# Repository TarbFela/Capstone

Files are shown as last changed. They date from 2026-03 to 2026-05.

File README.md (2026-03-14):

# A Temperature Programming Power & Control System for Desorption Energy Measurement Experiments

This is my electrical & computer engineering capstone as well as my honors thesis at the University of Maine. The hardware includes a number of power cards driven by PWM signals from a control board. Another board provides a serial interface to a Balzers mass spectrometer QMS 112 interface. The software for this project is largely written for the RP2350 microcontroller (like that found on the Raspberry Pi Pico 2) on a Pimoroni PGA2350 devboard/daughtercard. The PGA2350 plugs into the controller motherboard called ADPC for "Analog and Digital Processing and Control". This board incorporates, in addition to other instrumentation, MCP3462R and MCP3562R ADCs and an ADA4255 PGIA; all three of these provide SPI interfaces. I'm writing drivers for these devices which can be found in `src2/`. Functionalities are loosely (and currently rather haphazardly, with deprecation, poor compartmentalization, etc) broken out into separate headers/source files. 

I'll probably post hardware files somewhere at some point. The READMEs are currently acting as in-progress note-taking and as in-progress documentation. This project is meant to be used after I graduate by researchers in the Frederick Lab at FIRST. The code is roughly written with extensibility in mind.

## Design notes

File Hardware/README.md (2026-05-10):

# Temperature Programming & Control System Hardware

This is a collection of hardware documentation and resources. EasyEDA projects are downloaded and have been parsed by KiCad (do _not_ attempt to fabricate from these KiCad projects; fonts, etc have _not_ carried over). All datasheets used have been added. Any written hardware documentation is included.

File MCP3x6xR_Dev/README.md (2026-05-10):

# MCP3x6xR Development

Development for ADC-facing code on the ADPC board. 

Note that symlinks to the driver code need to be instantiated; git does not do this.

A `script.py` file is included to automate the serial interfacing tasks (as opposed to using a serial monitor);
this script also decodes the raw data stream. It takes as an argument the path of the usb device; on MacOS this is
something like `/dev/cu.usbmodem####`.

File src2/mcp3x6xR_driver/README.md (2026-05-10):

# MCP3x6xR Driver for RP2040/RP2350 [WIP]
This is a simple driver for the MCP3x6xR series ADCs that I will employ in my capstone project. They are SPI devices and I am using RP2350-based boards (namely, the Pimoroni PGA2350).

The driver abstracts basic SPI interactions and provides macros for the register addresses, command structure, and register fields for these ADCs. 
There is also a PIO program and corresponding driver to perform triggered reads of the ADC in continuous read mode. 
Functions pass ownership of GPIO pins between RP2350 SPI and PIO machines.

### Annoying, Sneaky Hardware Requirement
This series of ADCs seems to _require_ that the nIRQ pin be pulled to logic high externally. 
Without this step, the **ADC WILL NOT PERFORM CONVERSIONS**.

## Example Code

The `MCP3x6xR_Dev` directory has an example project using this driver. This project is based around a board I've designed called the ADPC;
if you intend to run this program on your own board you will have to define the RP2350 GPIO pins with `#define ADC_1_PIN_<name> <number>` and remove the references
to `ADPC_cfg.h` (you may even replace it with your own `<>_cfg.h`). 

The example code interfaces with a computer over USB; any serial port tool should work.
The device uses an ASCII interface except when collecting data, when it streams raw bytes over USB CDC. 
Providing a `"q"` input puts the RP2350 back in USB flash mode for further programming. 

`script.py` automates this interface. It requires that you know the path of the USB serial device (on MacOS this is `/dev/cu.usbmodem####`).

`graphing.py` graphs the received data. 

## Structure
This is a work in progress. I am still sorting out how best to define the types and how to structure functions, etc.

I perused the datasheet and wrote defines for a bunch of registers, addresses, etc based on information found therein. While some industry-standard headers (such as those from Raspberry Pi in their hardware/regs headers) use a structure wherein masks, LSB & MSB, and some values are provided for register fields, I am instead opting to provide OR-able field values. For example, in order to construct a value to be written to configuration register 0, you would simply:

```
uint8_t reg_val = MCP_CFG0_VREF_SEL_INTERNAL | MCP_CFG0_NO_PARTIAL_SHUTDOWN | MCP_CFG0_CLK_SEL_INTERNAL | MCP_CFG0_CURRENT_BIAS_SEL_0u0A | MCP_CFG0_ADC_MODE_STDBY;
```

_(In this particular case, some of these values are unnecessary. Some, however, are necessary, as a default value of 0 in those fields would cause a partial shutdown, e.g.)_

### Abstractions

The following functionalities have since been abstracted into higher-level functions (e.g. `mcp_write_regs()`)

### Reading and Writing

Reading and writing to registers requires a corresponding command type value in the command type field of the command byte. Most command types are 6 bits, but with read/write commands the top four bits correspond instead to the address information. For this reason I've structured the macros such that the read and write commands take an argument corresponding to the address of interest. An example command byte to perform a static (non-incrementing) read of configuration register 2 would be constructed like so:

```
uint8_t cmd = MCP_CMD_DEV_ADDR | MCP_CMD_ADC_REG_READ_STAT(MCP_REG_ADDR_CONFIG2);
```

### ADC MUX Input Selection

A similar macro to the one described above is used to select ADC inputs. Since each ADC input (+/-) may select from any of 15 sources and since the corresponding mux field values are the same between the positive and negative inputs, mux selection is done accordingly:

```
MCP_MUX_P_SEL(MCP_MUX_VAL_CH4) | MCP_MUX_N_SEL(MCP_MUX_VAL_CH0)
```

### Function return values

Because these ADCs read out their status while receiving the command byte, all ADC SPI commands are structured to return an `mcp_status_t` (name might change to be more specific). This is a single byte. Another function might be written to parse this byte. Bitfields are defined as `MCP_STAT_<...>`.

### A Note About Error Handling

Some effort has been made to catch loss of communication with the ADC. However, this was not a comprehensive effort by any means, so the behavior of the driver when communication is lost (e.g. if the ADC loses power) is thoroughly undefined!

## PIO

Included here is a PIO program to operate the device in continuous read mode, wherein the nIRQ pin on the ADC is pulled low when a conversion is ready. This triggers the PIO to initiate a SPI read (i.e. the PIO machine sends out 32 clock cycles and shifts the MISO data into a fifo). DMAs are daisy-chained. A globally accessible DMA buffer (`dma_buff_adc_0`) is provided. It is aligned such that the DMAs should automatically wrap upon filling their respective halves of the buffer. **It is important that the DMAs be provided an interrupt handler to clear interrupts**. See an example below:

```
void dma_irq_handler_1(void) {
    // clear the correct interrupt
    int culprit_is_a = dma_hw->ints0 & (1u << mpio_1.dma_a);
    if (culprit_is_a) {
        dma_hw->ints0 = 0x1 << (mpio_1.dma_a);
    }
    else {
        dma_hw->ints0 = 0x1 << (mpio_1.dma_b);
    }
}
```

### Start and stop functions

Start and stop functions are provided which _only_ enter or exit PIO mode. These functions **only** perform configuration tasks (e.g. for pins, dmas, pio, and spi) but do not communicate with the ADC. A separate SPI command should be sent to initiate conversions; once the nIRQ is pulled low, data is (likely) ready and the PIO start() function can be called. **KEEP CS ACTIVE AFTER THE SPI READ COMMAND!** (as per the datasheet).

```
    // write ADC mode
    uint8_t tx[2], rx[2];
    tx[0] = MCP_CMD_DEV_ADDR | MCP_CMD_ADC_REG_WRITE_INCR(MCP_REG_ADDR_CONFIG0);
    tx[1] = MCP_CFG0_VREF_SEL_INTERNAL | MCP_CFG0_NO_PARTIAL_SHUTDOWN | MCP_CFG0_CLK_SEL_INTERNAL | MCP_CFG0_ADC_MODE_CONV;
    gpio_put(ADC_1_PIN_CS,0); sleep_us(MCP_SLEEPTIME_US);
    spi_write_read_blocking(spi1, tx, rx, 2);
    sleep_us(MCP_SLEEPTIME_US); gpio_put(ADC_1_PIN_CS,1);
    // prepare to perform static read of ADC register
    tx[0] = MCP_CMD_DEV_ADDR | MCP_CMD_ADC_REG_READ_STAT(MCP_REG_ADDR_ADCDATA);
    // wait for first IRQ pin signal
    while(!gpio_get(ADC_1_PIN_IRQ)) tight_loop_contents();
    gpio_put(ADC_1_PIN_CS,0); sleep_us(MCP_SLEEPTIME_US);
    // perform first read.
    spi_write_read_blocking(spi1, tx, rx, 1);

    mcp_pio_start(&mpio_1);
```

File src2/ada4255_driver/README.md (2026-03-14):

# ADA4255 Driver for RP2040/RP2350 [WIP]

This is a simple SPI driver for the ADA4255 programmable-gain instrumentation amplifier (PGIA) that I am using as a thermocouple front-end for my thesis project.

## ADA4255 Command Structure

Refer to the ADA4255 datasheet for any further details. The command interface is very simple; there are two bytes (a third if you are use CRC; I don't wanna) where the first contains:

1. A read/write bit
2. A register address

And the second bit contains the data, streamed either of MOSI or MISO depending on the R/W bit provided in the previous byte.

This driver provides macros for all registers and fields (WIP: not actually done yet!). To figure out what they actually do, see the datasheet.

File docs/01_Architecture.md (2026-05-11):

# System Architecture

This document describes how the pieces fit together — both the hardware boards and the firmware layers within them. Read this before [`03_Driver_Reference.md`](03_Driver_Reference.md) or any of the deeper documents.

---

## The hardware stack

```
   ┌────────────────────────────┐         ┌────────────────────────────┐
   │          ADPC               │  UART  │           MSIF              │
   │   (control + measurement)   │◄──────►│   (mass spec interface)    │
   │                             │         │                            │
   │     PGA2350 (RP2350)        │         │     PGA2350 (RP2350)       │
   │     + 2× MCP ADCs           │         │     + DAC + ADC frontend   │
   │     + ADA4255 PGIA          │         │                            │
   └─────────────┬───────────────┘         └─────────────┬──────────────┘
                 │                                       │
        PWM ×12, PH_EN ×6                                │
                 │                          QMS-112 remote-control
                 ▼                                       ▼
   ┌─────────────────────┐   ┌─────────────────────┐    ┌──────────────────┐
   │     MPHB-002 #1     │   │    MPHB-002 #2 ...   │    │   Balzers QMS    │
   │  (2 buck converters │   │                      │    │      QMS-112     │
   │   per board, "1A"   │   │                      │    │ mass spectrometer│
   │   and "1B")         │   │                      │    │                  │
   └──────────┬──────────┘   └──────────────────────┘    └──────────────────┘
              │
              ▼
        ┌──────────┐
        │  HEATER  │ (load sits between the two buck converter outputs)
        └──────────┘
```

### The boards

**ADPC** — *Analog and Digital Processing and Control.* Hosts a PGA2350 daughtercard (the actual microcontroller, an RP2350) plus three precision SPI chips:

| Chip | Function | Notes |
|---|---|---|
| MCP3462R | 16-bit ADC — current sensing (ISNS) | Faster sample rate; this is the one in the control loop |
| MCP3562R | 24-bit ADC — temperature & voltage sensing (TSNS, VSNS) | Higher precision; scan mode across multiple inputs |
| ADA4255 | Programmable-gain instrumentation amplifier | Front-end for the thermocouple before it hits the MCP3562R |

The ADPC also has an MCP9808 I²C temperature sensor and a TS3A24159 analog switch for voltage-sense amp gain selection.

**MPHB-002** — *Multi-Phase H-Bridge, revision 002.* The power stage. Each MPHB-002 board provides **two** "B-style" channels (e.g. `1B` and `2B`). What we call an "H-bridge" here is actually **two buck converters with the load between them** — this lets us drive the heater both positively and negatively about a common-mode level. Up to three boards can be installed, giving six independent channels (`HB1A`, `HB2A`, `HB3A`, `HB1B`, `HB2B`, `HB3B`).

Each channel exposes:
- **Two PWM inputs** (`A` and `C`, conceptually one for each buck converter half)
- **One phase-enable input** (`PH_EN`) that turns the power stage on/off without changing PWM
- **Current-sense output** wired back to the ADPC's MCP3462R

**MSIF** — *Mass Spec Interface.* Communicates with a Balzers QMS-112 mass spectrometer via that instrument's "QDP" remote-control connector. Hosts its own PGA2350 plus analog I/O front-ends for the QMS-112's analog signals (FMASS+, etc.) and digital handshake lines (EMIS_OK, etc.). Currently a stub — see [`06_Extending_MSIF_UART.md`](06_Extending_MSIF_UART.md).

---

## The firmware stack (ADPC side)

The firmware is organized into roughly four layers, from low-level hardware drivers up to the user-facing shell. Each layer builds on the one below; you can usually do new work at one layer without disturbing the others.

```
  Layer            File(s)                              Purpose
  ─────────────────────────────────────────────────────────────────────────────
   USER SHELL     adpc_data_streaming.c                 main(), boot, reboot
                  adpc_app.[ch]                         line buffer, dispatch
                                                                  
   COMMANDS       adpc_app_funcs.[ch]                   isp, ictl, rstream,
                                                        irun, irun stream,
                                                        adpc_init
                                                                  
   CONTROL LOOP   adpc_core1.[ch]                       runs on core 1:
                                                        PI current controller
                                                                  
   DRIVERS        ADPC_Dev/ADPC_ADC.[ch]                MCP ADC config
                  ADPC_Dev/adpc_gpio_pwm.[ch]           MPHB PWM / PH_EN
                  ADPC_Dev/adpc_vsns.[ch]               VSNS amp gain pin
                  mcp3x6xR_driver/mcp3x6xR.[ch]         raw SPI to ADC
                  mcp3x6xR_driver/mcp_pio.[ch]          PIO + DMA streaming
                  mcp3x6xR_driver/mcp_pio.pio           PIO assembly program
                  ada4255_driver/ada4255.[ch]           raw SPI to PGIA
                                                                  
   PIN MAP        ADPC_Dev/ADPC_cfg.h                   every #define for a pin
```

`ADPC_cfg.h` is the single source of truth for which physical pin does what. Any new feature that touches a pin should reference symbols from this file, not hardcoded GPIO numbers.

---

## What runs where: cores

The RP2350 has two CPU cores. This firmware uses both:

- **Core 0** — runs `main()`. Owns the USB CDC connection (the shell), the DMA interrupt handlers (which deposit data into RAM), and all "slow" command handling. Lives inside `app_shell_task()` in a loop.
- **Core 1** — *only running when closed-loop current control is active.* Runs `core1_ictl()` which polls the DMA write position, computes a moving-average current, runs a PI controller, and updates the PWM output level. Started/stopped from core 0 via `app_cmd_ictl()`.

The two cores communicate through a hardware FIFO. Core 0 sends `MC_FIFO_STOP_FLAG` to ask core 1 to exit cleanly; core 1 responds with an acknowledgement before exiting.

They also share `ui_state` (declared `volatile`) for things like the current setpoint and the most recently computed level. **Race conditions are a real risk here** — see the hazards document.

---

## What runs where: DMA, PIO, interrupts

The ADC sample path is the heart of the system. Here's the chain, end to end:

```
  ADC pulls nIRQ low ──► PIO state machine wakes up
                         (one per ADC: pio0/sm0 and pio1/sm0)
                                  │
                                  │ shifts 32 clock pulses, captures MISO
                                  ▼
                         PIO RX FIFO has one 32-bit word
                                  │
                                  │ DREQ triggers DMA
                                  ▼
                         DMA writes into ring buffer
                         (dma_a or dma_b, ping-pong, chained to each other)
                                  │
                                  │ when buffer half is full:
                                  ▼
                         DMA fires IRQ on the chosen line
                                  │
                                  │ DMA_IRQ_0 → handler_0   (for ADC 0)
                                  │ DMA_IRQ_1 → handler_1   (for ADC 1)
                                  ▼
                         Handler clears the IRQ flag and updates
                         dma0_last_written / dma1_last_written
                                  │
                                  │ Either core can poll these globals
                                  ▼
                         Consumer (core 0 streaming OR core 1 control)
```

A few subtleties worth knowing now and revisiting in [`05_DMA_PIO_Streaming.md`](05_DMA_PIO_Streaming.md):

- Each ADC gets its **own pair of DMA channels** (A and B), wired as a ping-pong. When A fills, it chains to B and vice versa. Both write into a single contiguous buffer of size `2 × DMA_BUFF_SIZE` so it looks like one circular buffer.
- The buffers are **aligned in memory** to a power-of-two boundary so that DMA *ring mode* automatically wraps the write pointer back to the start of each half. This avoids needing software wrap-around.
- The ADC IRQ pin **must** be pulled high externally — the MCPs won't run conversions otherwise. This trips up most people once.
- `dma0_last_written` is `0` if nothing's been written yet, `1` if buffer A finished, `2` if buffer B finished. Whichever is "current" (i.e. the *other* one) can be inferred.

---

## Data flow during normal operation

The firmware can be in one of several modes. Each is initiated by a shell command:

| Mode | Started by | What core 0 does | What core 1 does | Hardware state |
|---|---|---|---|---|
| Idle | (default after boot) | Shell prompt | not running | PWM off, PH_EN off |
| Initialized | `start` | Shell prompt | not running | PWM running but PH_EN may be off |
| Open-loop level set | `level <n>` | Shell prompt | not running | PWM at fixed differential level |
| Closed-loop current | `ictl` | Shell prompt | PI control on isns | PWM dynamically adjusted |
| Raw data stream | `rstream` | Stream ADC bytes via USB CDC | unchanged | unchanged |
| Program run | `irun` | Step setpoints over time | PI control on isns | PWM dynamically adjusted |
| Program run + stream | `irun stream` | Step setpoints AND stream | PI control on isns | PWM dynamically adjusted |

Note that `rstream` and `irun stream` *do not* alter the control state; they just attach the USB CDC pipe to the DMA buffers and start spitting bytes. The control loop and the streaming output are independent consumers of the same DMA-produced data.

---

## How to think about adding a feature

Pick the layer that matches what you're adding:

| Adding… | Layer | Files to touch |
| --- | ----- | --- |
| A new shell command | USER SHELL → COMMANDS | `adpc_app.c`, `adpc_app_funcs.[ch]` |
| A new mode of using existing peripherals | COMMANDS | `adpc_app_funcs.[ch]` |
| A change to how the controller computes its output | CONTROL LOOP | `adpc_core1.c` |
| A new chip on an existing bus (SPI, I²C) | DRIVERS | new driver folder; reference from `adpc_app_funcs.c` |
| A new pin assignment | PIN MAP | `ADPC_cfg.h` |
| A new high-speed data source (e.g. mass spec ADC over UART) | DRIVERS → COMMANDS | new driver + new app command; see [`06_Extending_MSIF_UART.md`](06_Extending_MSIF_UART.md) |

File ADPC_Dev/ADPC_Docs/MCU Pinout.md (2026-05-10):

# ADPC MCU Pinout (RP2350)

This table lists the pins of the PGA2350, the nets which they are connected to (typically descriptive of devices such as the ADCs, temperature sensors, etc.) and then their appropriate GPIO Function configuration. See the RP2350 Datasheet Section 1.2.3 for reference (replicated in this directory as a CSV). 

## "Notes"
The "Notes" column lists—in addition to some notes—the possibility of some pins to be used as SPI pins.
### SPI Flash Fix
The **bold** entries refer to a plan to use the HB-3B connector (6-pin MPHB-002 connector) as a SPI connector to a W25Q128 flash chip (on a breakout board such as the one produced by Adafruit). This plan requires soldering a wire from an unused PGA2350 pin to an unused HB-B3 pin. This plan may not be necessary if there is adequate storage on the PGA2350's flash chip (also a W25Q128) and if flash writes to this chip do not interfere with other code. This plan would require that the relevant SPI pins only be configured as SPI when the devices on the same spi_n channel are not being used in that way; i.e. when the MCP ADC SPI pins are under "ownership" of the PIO machines which perform data-ready-triggered "SPI" reads. The MCP SPI pins should not attempt to reclaim the SPI pins if their ownership has been transfered to the SPI flash chip. Some construct should be implemented to organize this ownership.

### CS Pins

SPI chip-select pins are configured as GPIO outputs and manually set and reset (with some delay) in code before and after SPI interactions.

### PIO

PIO machines are used to perform triggered SPI-like reads of the two MCP3x62R ADCs. Other ADC communications use the RP2350's SPI blocks. Pin "ownership" is transferred between the two machines according to the `mcp_pio` driver code.

## Pinout

| PIN | NET | FUNCTION | NOTES |
|---|---|:---|---|
| GPIO 0		  | ADC_16_SPI_SDO 		 | SPI0 | |
| GPIO 1		  | ADC_16_MCLK & ADC_24_MCLK 		 | PWM 0A	 | |
| GPIO 2		  | ADC_16_IRQ 		 | SIO / PIO | |
| GPIO 3		  | ADC_16_SPI_SDI 		 | SPI0 / PIO	 | |
| GPIO 4		  | INAMP_GPIO2_CALIB_BUSY 		 | SIO | |
| GPIO 5		  | ADC_16_SPI_CS 		 | SPI0 / SIO |
| GPIO 6		  | ADC_16_SPI_SCK 		 | SPI0 / PIO | |
| GPIO 7		  | INAMP_SPI_CS 		 | SIO | |
| GPIO 8		  | INAMP_GPIO3_FAULT 		 | SIO | |
| GPIO 9		  | ADC_24_IRQ 		 | SIO / PIO | |
| GPIO 10		 | TMP_12C_SDA 		 | I2C1 | |
| GPIO 11		 | INAMP_SPI_SDI & ADC_24_SDI 	 | SPI1 / PIO | |
| GPIO 12		 | INAMP_SPI_SDO & ADC_24_SDO 	 | SPI1		 | |
| GPIO 13		 | ADC_24_SPI_CS 		 | SPI1			 | |
| GPIO 14		 | INAMP_SPI_SCLK & ADC_24_SCLK 	 | 	SPI1 / PIO		 | |
| GPIO 15		 | TMP_12C_SCL 		 | I2C1			 | |
| GPIO 16		 | VSNS_AMP_GAIN_SEL 		 | SIO		 | |
| GPIO 17		 | MPHB_VDET_3 		 | SIO		 | |
| GPIO 18		 | PWM_A_1 		 | PWM 1A			 | SPI0 SCK |
| GPIO 19		 | PWM_C_1 		 | PWM 1B			 | SPI0 TX |
| GPIO 20		 | PWM_B_1 		 | PWM 2A			 | SPI0 RX |
| GPIO 21		 | PWM_D_1 		 | PWM 2B			 | SPI0 CSn |
| GPIO 22		 | PWM_C_2 		 | PWM 3A			 | SPI0 SCK |
| GPIO 23		 | PWM_A_2 		 | PWM 3B			 | SPI0 TX |
| GPIO 24		 | PWM_D_2 		 | PWM 4A			 | SPI1 RX |
| GPIO 25		 | PWM_B_2 		 | PWM 4B			 | SPI1 CSn |
| GPIO 26		 | PWM_B_3 		 | PWM 5A			 | **SPI1 SCK** SPI Flash Fix: HB-3 Pin 2 = SPI SCK |
| GPIO 27		 | PWM_D_3 		 | PWM 5B			 | **SPI TX** SPI Flash Fix: HB-3 Pin 1 = SPI MOSI |
| GPIO 28		 | PWM_A_3 		 | PWM 6A			 | SPI1 RX |
| GPIO 29		 | PWM_C_3 		 | PWM 6B			 | SPI1 CSn |
| GPIO 30		 | MPHB_VDET_2 		 | SIO		 | |
| GPIO 31		 | MPHB_VDET_1 		 | SIO		 | |
| GPIO 32		 | MCU_INDICATOR_LED_1 		 | SIO		 | |
| GPIO 33		 | UART_RX 		 | UART0		 | |
| GPIO 34		 | UART_TX 		 | UART0		 | |
| GPIO 35		 | PH_EN_A2 / MPHB-002 Detect 		 | SIO | SPI0 TX		Open-Drain or Input/Output Low to see 3.3V when MPHB-002 is connected and powered and to PH-disable, resp.  |
| GPIO 36		 | PH_EN_B2 / MPHB-002 Detect 		 | SIO | SPI0 RX		Open-Drain or Input/Output Low to see 3.3V when MPHB-002 is connected and powered and to PH-disable, resp.  |
| GPIO 37		 | PH_EN_B1 / MPHB-002 Detect 		 | SIO | SPI0 CSn		Open-Drain or Input/Output Low to see 3.3V when MPHB-002 is connected and powered and to PH-disable, resp. |
| GPIO 38		 | PH_EN_A3 / MPHB-002 Detect 		 | SIO | SPI0 SCK		Open-Drain or Input/Output Low to see 3.3V when MPHB-002 is connected and powered and to PH-disable, resp. |
| GPIO 39		 | PH_EN_A1 / MPHB-002 Detect 		 | SIO | SPI0 TX		Open-Drain or Input/Output Low to see 3.3V when MPHB-002 is connected and powered and to PH-disable, resp.  |
| GPIO 40		 | PH_EN_B3 / MPHB-002 Detect 		 | SIO | **SPI1 RX** SPI Flash Fix: HB-3 Pin 6 = SPI MISO |
| GPIO 41		 | MCU1_41 		 | _none_			 | **SIO CSn** SPI Flash Fix: HB-3 Pin 5 = SPI CSn (_NOTE: REQUIRES PCB WIRE REWORK!!!_) |
| GPIO 42		 | 12C_HEADER_SDA 		 | I2C1			 | |
| GPIO 43		 | 12C_HEADER_SCL 		 | I2C1			 | |
| GPIO 44		 | MCU_ADC_4 		 | ADC				 | SPI1 RX |
| GPIO 45		 | MCU_ADC_5 		 | ADC				 | |
| GPIO 46		 | MCU_ADC_6 		 | ADC				 | |
| GPIO 47		 | MCU1_47 		 | _none_			 | |
| 3V3		 | MCU_3V3 		 | | |
| 3V3N		 | MCU1_3V3EN 		 | | |
| ADCVRF		  | MCU1_ADCVREF 		 | | |
| BOOTSL		  | MCU1_BOOTSEL 		 | | |
| GND		 | GND 		 | | |
| RUN		 | MCU1_RUN 		 | | |
| SWCLK		 | MCU1_SWCLK 		 | | |
| SWDIO		 | MCU1_SWDIO 		 | | |
| USB+		 | USB_D+ 		 | | |
| USB-		 | USB_D- 		 | | |
| VBUS		 | MCU_VBUS 		 | | |
|

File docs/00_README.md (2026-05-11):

# Developer Documentation — Capstone TPS System

This documentation set is for developers continuing work on the Temperature Programming Power & Control System after Maxim Laplante's capstone. The intended audience is **scientists with some programming exposure**, not embedded-systems veterans. C-specific concepts and RP2350-specific concepts are explained when first introduced.

If you only have time for one read, read [`01_Architecture.md`](01_Architecture.md) and [`02_Safety_and_Hazards.md`](02_Safety_and_Hazards.md). Then come back for the rest as needed.

---

## What this project is

A power-and-measurement system for **temperature-programmed desorption (TPD) experiments** in the Frederick Lab. Two custom PCBs run the show:

- The **ADPC** ("Analog and Digital Processing and Control") drives heater current and measures sample temperature.
- The **MSIF** ("Mass Spec Interface") talks to a Balzers QMS-112 mass spectrometer.

Both boards host a **PGA2350** daughtercard (an RP2350-based microcontroller from Pimoroni — same chip as the Raspberry Pi Pico 2). Power-stage hardware is on separate **MPHB-002** cards, driven by PWM from the ADPC.

The ADPC firmware is mature; the MSIF firmware is a stub awaiting a developer.

---

## Where to find what

| If you want to… | Read |
| --- | --- |
| Understand the system architecture | [`01_Architecture.md`](01_Architecture.md) |
| Avoid letting magic smoke out of the hardware | [`02_Safety_and_Hazards.md`](02_Safety_and_Hazards.md) |
| Use the existing low-level drivers (ADC, PGIA, H-bridge) | [`03_Driver_Reference.md`](03_Driver_Reference.md) |
| Understand the shell, app state, and command dispatch | [`04_Application_Layer.md`](04_Application_Layer.md) |
| Understand how high-speed data acquisition works | [`05_DMA_PIO_Streaming.md`](05_DMA_PIO_Streaming.md) |
| Add UART + DAQ between the ADPC and MSIF | [`06_Extending_MSIF_UART.md`](06_Extending_MSIF_UART.md) |
| Just use the device (operator-level) | [`HOW_TO_ADPC_Streaming.md`](../ADPC_Dev/ADPC_Docs/HOW_TO_ADPC_Streaming.md) |

---

## Directory map

```
Capstone/
├── ADPC_Data_Streaming/       ← Main firmware. Build target: adpc_streaming.uf2
│   ├── adpc_data_streaming.c  ← main() entry
│   ├── adpc_app.[ch]          ← shell, dispatch, app state
│   ├── adpc_app_funcs.[ch]    ← command implementations
│   ├── adpc_core1.[ch]        ← closed-loop current controller (runs on core 1)
│   ├── ada4255_driver/        ← PGIA driver
│   ├── mcp3x6xR_driver/       ← MCP ADC + PIO/DMA streaming driver
│   ├── script.py              ← host-side shell wrapper
│   ├── graphing.py            ← log file viewer
│   └── CMakeLists.txt
│
├── ADPC_Dev/                  ← Shared driver code referenced by the firmware
│   ├── ADPC_ADC.[ch]          ← Configures both MCP ADCs for the ADPC
│   ├── ADPC_cfg.h             ← All pin definitions for the ADPC board
│   ├── adpc_gpio_pwm.[ch]     ← MPHB H-bridge PWM control (the high-power part)
│   ├── adpc_vsns.[ch]         ← Voltage-sense amp gain selection
│   └── ADPC_Docs/             ← Pinout, streaming how-to, etc.
│
├── MSIF_dev/                  ← Skeleton MSIF firmware. NEEDS DEVELOPMENT.
│   ├── main.c                 ← Currently just waits for keypress
│   ├── msif_gpio.[ch]         ← Empty stub
│   ├── MSIF_cfg.h             ← Empty stub for pin definitions
│   └── MSIF_Docs/             ← Schematic PDFs, getting-started doc
│
├── src2/                      ← OLDER drafts. Reference only — do not build from here.
├── MCP3x6xR_Dev/              ← Standalone MCP test project (predates ADPC_Data_Streaming)
├── ADA4255_Dev/               ← Standalone ADA test project
├── W25_dev/                   ← External flash test code (not currently used)
└── Hardware/                  ← KiCad / EasyEDA files, schematics, datasheets
```

`src2/` and the various `*_Dev/` folders are early drafts kept for reference. The active code lives in `ADPC_Data_Streaming/` and `ADPC_Dev/`. New MSIF code goes in `MSIF_dev/`.

---

## A short C / RP2350 vocabulary

| Term | What it means here |
| ---- | --- |
| **GPIO** | A pin on the microcontroller that can be set to high (3.3 V) or low (0 V), or read as an input. The RP2350 has ~48 of them. |
| **PWM** | Pulse-Width Modulation. A square wave whose duty cycle (% of time high) sets an analog-like output. Used to drive the H-bridges. |
| **SPI** | A 4-wire digital communication protocol (clock, two data lines, chip-select). All three precision chips on the ADPC (two ADCs, one PGIA) talk SPI. |
| **UART** | A 2-wire serial protocol (TX, RX). Will be used between the ADPC and MSIF. |
| **DMA** | Direct Memory Access — hardware that copies bytes between peripherals and RAM without involving the CPU. Used to stream ADC samples into memory at high speed. |
| **PIO** | A small programmable state machine block on the RP2350 that can run custom bit-banged protocols. Used here to read the ADCs the moment they signal "data ready." |
| **`volatile`** | A C keyword telling the compiler "this variable may be changed by hardware or another core — don't optimize accesses to it away." Used on the DMA-touched buffers and on `ui_state`. |
| **IRQ / ISR** | Interrupt request / interrupt service routine. A function that runs in response to a hardware event (e.g. "DMA finished a buffer"). Keep them short. |
| **Core 0 / Core 1** | The RP2350 has two CPU cores. Core 0 runs main + the shell. Core 1, when launched, runs the closed-loop current controller. |
| **BOOTSEL / USB flash mode** | The state the RP2350 enters when you want to flash new firmware. The `q` command in the shell forces this. |

---

## Build & flash

From either `ADPC_Data_Streaming/` or `MSIF_dev/`:

```bash
mkdir build && cd build
export PICO_SDK_PATH=/path/to/pico-sdk
cmake -DPICO_BOARD=pico2 ..
make
```

This produces a `.uf2` file. To flash:

1. Hold the **BOOTSEL** button on the PGA2350 while plugging it into USB (or send `q` to a running firmware).
2. The board mounts as a USB drive.
3. Drag the `.uf2` file onto the drive. It will flash and reboot automatically.

The "RUN" button on the ADPC resets the board without entering BOOTSEL — useful for unsticking a hung firmware without reflashing.

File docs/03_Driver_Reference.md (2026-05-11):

# Driver Reference

This document covers the **low-level drivers** — the code that talks directly to hardware. There are four:

| Driver | Files | Talks to |
|---|---|---|
| MCP ADC | `mcp3x6xR_driver/mcp3x6xR.[ch]` | Either MCP ADC (16-bit ISNS or 24-bit TSNS/VSNS) over SPI |
| MCP PIO | `mcp3x6xR_driver/mcp_pio.[ch]`, `mcp_pio.pio` | The same ADCs but in *streaming* mode via PIO + DMA |
| ADA4255 PGIA | `ada4255_driver/ada4255.[ch]` | The programmable-gain amplifier |
| MPHB GPIO/PWM | `ADPC_Dev/adpc_gpio_pwm.[ch]` | The MPHB-002 power boards (PWM + PH_EN pins) |

There is also a thin wrapper around the two MCP ADCs in `ADPC_Dev/ADPC_ADC.[ch]` that knows about the *specific* ADPC board (which pins, what configuration). Most app code should call into this wrapper rather than the raw MCP driver.

---

## MCP ADC driver (`mcp3x6xR_driver/`)

The MCP3x6xR family is a series of high-resolution sigma-delta ADCs with an SPI interface and a "data ready" interrupt pin. This driver provides two modes of operation:

1. **One-shot / configuration mode** via the raw SPI driver in `mcp3x6xR.[ch]`. Used during startup to write configuration registers.
2. **Continuous streaming mode** via the PIO+DMA driver in `mcp_pio.[ch]`. Used during data acquisition to capture samples without CPU intervention.

The two are mostly independent. The configuration code uses the RP2350's hardware SPI block; the streaming code uses a PIO state machine that *physically reuses the same pins* but takes them away from the SPI hardware when streaming starts. Pin ownership flips back and forth.

### Key types

```c
typedef struct mcp_info_t {
    spi_inst_t *spi;       // which SPI hardware block (spi0 or spi1)
    int mosi, miso, cs, sck, nirq, mclk;   // pin numbers
    mcp_cfg_t cfg;         // the configuration most recently written
} mcp_info_t;

typedef struct mcp_pio_t {
    bool initialized, running;
    PIO pio;               // pio0 or pio1
    uint sm;               // state machine number (0..3)
    mcp_info_t *mcp_info;  // back-pointer to the SPI-level state
    uint dma_a, dma_b;     // the two ping-pong DMA channels
    uint irqn;             // DMA_IRQ_0 or DMA_IRQ_1
    uint32_t *buff;        // pointer to the 2× DMA_BUFF_SIZE buffer
} mcp_pio_t;
```

You typically don't construct these directly. The ADPC-level wrapper (`ADPC_ADC.c`) instantiates two global pairs (`mcp_0`/`mpio_0` and `mcp_1`/`mpio_1`) and you use those.

### Key functions

**Configuration (raw SPI mode):**

```c
mcp_status_t mcp_spi_init(mcp_info_t *s, spi_inst_t *spi,
                          int mosi, int miso, int cs, int sck, int nirq, int mclk);
```
Sets up the GPIO pins for SPI, initializes the SPI block, prepares the nIRQ and MCLK pins. Does not yet start the ADC.

```c
mcp_status_t mcp_configure(mcp_info_t *s, mcp_cfg_t *cfg);
```
Writes a full set of configuration registers (CONFIG0..3, MUX, SCAN, etc.). Build the `mcp_cfg_t` by OR-ing the field macros — see `ADPC_ADC.c` for example.

```c
mcp_status_t mcp_mclk_init(mcp_info_t *s, uint32_t freq);
```
Generates the master clock for the ADC on a PWM pin. The freq parameter is in Hz; typical is 15 MHz.

**Streaming (PIO+DMA mode):**

```c
void mcp_pio_init(mcp_pio_t *s, mcp_info_t *mcp,
                  uint32_t *sample_buff, void (*dma_handler)(void));
```
Claims a PIO state machine, loads the PIO assembly program, claims two DMA channels, chains them ping-pong style, and registers your `dma_handler` for the DMA's IRQ line. **Can only be called twice** in the lifetime of the firmware — see the safety doc.

```c
void mcp_pio_start(mcp_pio_t *s);
void mcp_pio_stop(mcp_pio_t *s);
```
Hands SCK/MISO/nIRQ pin ownership to the PIO and starts the state machine (`start`) or returns ownership to SPI and stops everything (`stop`). The ADC itself must already be in continuous-conversion mode before `start` (see `adpc_adc_start` for the right sequence).

### Example: configuring the 16-bit ADC

Done once at boot in `ADPC_ADC.c`:

```c
mcp_cfg_t cfg;
gpio_pull_up(ADC_0_PIN_IRQ);          // external pull-up assumed too
mcp_spi_init(&mcp_0, ADC_0_SPI,
             ADC_0_PIN_MOSI, ADC_0_PIN_MISO,
             ADC_0_PIN_CS, ADC_0_PIN_SCK,
             ADC_0_PIN_IRQ, ADC_MCLK_PIN);

mcp_pio_init(&mpio_0, &mcp_0, dma_buff_adc_0, dma_irq_handler_0);

cfg.cfgs[0] = MCP_CFG0_VREF_SEL_INTERNAL
            | MCP_CFG0_NO_PARTIAL_SHUTDOWN
            | MCP_CFG0_CLK_SEL_INTERNAL
            | MCP_CFG0_ADC_MODE_STDBY;
cfg.cfgs[1] = MCP_CFG1_AMCLK_PRESCALE_NONE | MCP_CFG1_OSR_2048;
cfg.cfgs[2] = MCP_CFG2_BIAS_CURRENT_SEL_1 | MCP_CFG2_ADC_GAIN_SEL_1
            | MCP_CFG2_AUTO_ZERO_REF_EN | 0x1;
cfg.cfgs[3] = MCP_CFG3_CONV_MODE_CONTINUOUS | MCP4_CFG3_DATA_FORMAT_32_SGN;
cfg.input_mode = MCP_MUX_MODE;
cfg.mux_sel = MCP_MUX_P_SEL(MCP_MUX_VAL_CH0) | MCP_MUX_N_SEL(MCP_MUX_VAL_CH1);
mcp_configure(&mcp_0, &cfg);
mcp_mclk_init(&mcp_0, 15000000);
```

To start it streaming, call `adpc_adc_start(&mpio_0)` later.

### Hazards

- Don't `mcp_pio_init` more than twice. (See safety doc.)
- Configuration register meanings differ between MCP3462R (16-bit) and MCP3562R (24-bit), particularly the data format field. Use the `MCP4_*` macros for the 16-bit chip and `MCP5_*` for the 24-bit. Mismatch silently produces garbage data.
- After `mcp_pio_stop`, the pins return to GPIO_FUNC_SPI. If you want to do something else with them (e.g. use them for unrelated SPI traffic), set the pin function explicitly.

---

## ADPC ADC wrapper (`ADPC_Dev/ADPC_ADC.[ch]`)

Thin board-aware wrapper that does the right configuration for the *specific ADCs on the ADPC board*. This is what application code should call, not the raw MCP driver.

### Globals

```c
extern mcp_info_t mcp_0;   extern mcp_pio_t mpio_0;   // 16-bit ISNS ADC
extern mcp_info_t mcp_1;   extern mcp_pio_t mpio_1;   // 24-bit TSNS/VSNS ADC
```

### Functions

```c
int adpc_adc_init(void (*dma_handler_1)(void), void (*dma_handler_0)(void));
```
Configures both ADCs. You provide the two DMA interrupt handlers (your code in `adpc_app_funcs.c` does this). Returns `0` on success.

```c
int adpc_adc_start(mcp_pio_t *s);
```
Brings the specified ADC to streaming-ready state: writes the "start conversions" command, waits for the first data-ready pulse, performs the first read, and hands pin ownership to the PIO state machine. After this returns, DMA samples are flowing into RAM.

### Note on the 24-bit ADC's scan mode

ADC 1 is configured in *scan mode* with `MCP_SCAN_SEL_BIT_DIFF_A | MCP_SCAN_SEL_BIT_DIFF_B`. This means the chip cycles through the two differential channel pairs by itself, emitting one sample per channel per cycle. The data format `MCP5_CFG3_DATA_FORMAT_32_CHID_SGN4_24` packs the channel ID into the upper 4 bits of each 32-bit word, so when you read a sample you can tell which channel it came from. The host-side `script.py` decodes this.

---

## ADA4255 PGIA driver (`ada4255_driver/`)

The ADA4255 is a programmable-gain instrumentation amplifier with an SPI configuration interface. It sits on the same SPI bus as the 24-bit ADC (different CS pin) and amplifies the thermocouple signal before it hits the ADC.

The driver is simple — it's almost entirely register macros plus a thin SPI wrapper.

### Key functions

```c
void ada_spi_init(ada_info_t *s, spi_inst_t *spi,
                  int mosi, int miso, int cs, int sck);
```
Configures the SPI for the PGIA. Run **after** you've configured the SPI for ADC 1 (they share the bus) but **before** any ADC streaming — both can't talk on the bus at the same time.

```c
int ada_input_select(ada_info_t *s, uint input);
```
Selects which input pair the PGIA reads from. Values: `ADA_INPUT_1`, `ADA_INPUT_2`, `ADA_INPUT_TEST_MUX`, `ADA_INPUT_SHORT`. Use `ADA_INPUT_SHORT` for offset calibration; use `ADA_INPUT_TEST_MUX` for testing.

```c
int ada_input_gain_select(ada_info_t *s, uint input_gain);
```
Sets the PGIA gain. Values range from `ADA_INPUT_GAIN_DIV_16` through `ADA_INPUT_GAIN_128`. The thermocouple front-end uses `ADA_INPUT_GAIN_32`.

```c
uint8_t ada_read_reg(ada_info_t *s, uint8_t addr);
void ada_write_reg(ada_info_t *s, uint8_t addr, uint8_t val);
```
Direct register access. Useful for reading status bits or for any function not yet wrapped in a helper.

```c
uint8_t ada_check_digital_error(ada_info_t *s);
void ada_clear_digital_error(ada_info_t *s, uint8_t bits);
uint8_t ada_check_analog_error(ada_info_t *s);
void ada_clear_analog_error(ada_info_t *s, uint8_t bits);
```
The PGIA latches digital and analog error conditions in two status registers. These read and clear them. Worth polling periodically if you're tracking unusual fault behavior.

### Example: ADPC initialization

```c
ada_info_t ada;
ada_spi_init(&ada, PGIA_SPI,
             PGIA_PIN_MOSI, PGIA_PIN_MISO,
             PGIA_PIN_CS, PGIA_PIN_SCK);

ada_input_select(&ada, ADA_INPUT_1);
ada_input_gain_select(&ada, ADA_INPUT_GAIN_32);
```

### Hazards

- The PGIA shares its SPI bus with ADC 1. If you call `ada_*` functions while the PIO is streaming ADC 1, the bus contention will corrupt both. **Stop the ADC PIO before reconfiguring the PGIA.**
- Default gain after a soft reset is 1, not 32. Re-apply gain after any reset.

---

## MPHB GPIO/PWM driver (`ADPC_Dev/adpc_gpio_pwm.[ch]`)

This is the highest-stakes driver — it controls the actual high-current power output. Read [`02_Safety_and_Hazards.md`](02_Safety_and_Hazards.md) before using it for anything beyond what's already in the firmware.

The MPHB-002 boards expose three pin types per channel:
- Two PWM pins (e.g. `PWM_B_1_PIN`, `PWM_D_1_PIN` for channel `HB1B`) for the two buck converter halves.
- One `PH_EN` pin that gates the power stage.

The RP2350's PWM peripheral assigns these to *slices* and *channels*. Each slice has two channels (A and B), and one slice drives both PWMs for one MPHB channel.

### Key type

```c
typedef enum {HB1A, HB2A, HB3A, HB1B, HB2B, HB3B} mphb_port_t;
```

Six possible channels. The "A" variants are the *first* H-bridge on each MPHB-002 board and the "B" variants are the *second*.

### Initialization

```c
void mphb_gpio_init(mphb_port_t i);
```
Set up the PWM hardware and the `PH_EN` pin for one channel. The PWM is configured at 100 kHz with a wrap count of `MPHB_PWM_WRAP = 1000` (so "level" values range 0–1000 representing 0–100% duty). PWM is initialized **disabled**, PH_EN is initialized **low**. Call this for every channel you want to use before any of the level/enable functions below.

```c
void mphb_setup_multiphase_masked(uint32_t phases_mask);
```
Assigns equal phase offsets across the channels indicated by the mask. With 3 active channels the phase shifts are 0°, 120°, 240° — this reduces ripple and EMI by interleaving the switching events. Pass a mask like `(1U << HB1B) | (1U << HB2B) | (1U << HB3B)`.

### Level control (output)

```c
void mphb_set_levels(mphb_port_t i, uint level_A, uint level_C);
void mphb_set_levels_all(uint level_A, uint level_C);
```
Set the two PWM levels directly. Each is 0..1000. **Symmetric levels (`level_A == level_C`) produce zero net output.** Asymmetric levels produce a net voltage proportional to their difference.

```c
void mphb_set_dlevel(mphb_port_t i, int dlevel);
void mphb_set_dlevel_all(int dlevel);
```
Set a **differential** level about a common-mode duty cycle (default 50%). `dlevel = 0` → zero output. Positive `dlevel` → drive one way; negative → drive the other. This is the preferred interface — it's symmetric about the common mode and easier to reason about.

```c
void mphb_set_dlevel_all_spatial_dithering(float d);
```
Distributes the requested level *unevenly* across active phases to get sub-integer effective resolution. The input is a *fraction*, not an integer — typical range `-0.3` to `+0.3` (which the closed-loop controller clamps to). This is what `core1_ictl()` uses to push the controller's chatter down below the thermocouple noise floor.

### Enable control

```c
void mphb_set_ph_en(mphb_port_t i, bool enable);
void mphb_set_ph_en_all(bool enable);
```
The PH_EN gate. Toggles the power stage on/off without disturbing the PWM signal.

```c
void mphb_set_pwm_en(mphb_port_t i, bool enable);
void mphb_set_pwm_en_all(bool enable);
```
Enables/disables the PWM peripheral itself. When PWM is disabled, the output pins idle low. When re-enabling, the counter resumes from where it left off (you probably want to also reapply the multiphase setup).

### A typical safe startup sequence

```c
// 1. Initialize each channel you intend to use
mphb_gpio_init(HB1B);
mphb_gpio_init(HB2B);
mphb_gpio_init(HB3B);

// 2. Phase-shift them for multiphase operation
mphb_setup_multiphase_masked((1U << HB1B) | (1U << HB2B) | (1U << HB3B));

// 3. Make sure outputs are at zero before enabling power
mphb_set_dlevel_all(0);

// 4. Enable PWM (output pins now show 50%/50% duty — zero differential)
mphb_set_pwm_en_all(true);

// 5. THEN enable the power stage
mphb_set_ph_en_all(true);

// 6. Now you can change levels safely
mphb_set_dlevel_all(20);    // small positive output
```

To shut down safely, reverse the order: drop levels to zero, disable PH_EN, then disable PWM.

### Hazards

- Re-read [§1 of the safety doc](02_Safety_and_Hazards.md#1-always-disable-ph_en-before-reconfiguring-pwm).
- `mphb_set_pwm_en_all` only operates on `initialized` channels — channels you haven't `mphb_gpio_init`ed are silently skipped. This is usually what you want, but worth knowing.
- The "multiphase" setup is recomputed from scratch each call. If you bring a new channel online mid-run, you must call `mphb_setup_multiphase_masked` again with the full set of active channels.

---

## VSNS gain switch (`ADPC_Dev/adpc_vsns.[ch]`)

A tiny driver for the analog switch that selects between two gain settings on the voltage-sense amplifier.

```c
void adpc_vsns_init();
void adpc_vsns_select_gain(int gain_sel);
```

`gain_sel` is `VSNS_AMP_GAIN_SEL_0V196` or `VSNS_AMP_GAIN_SEL_0V476` (defined in `ADPC_cfg.h`). Silently does nothing if you pass anything else.

That's the whole driver. Useful as an example of the minimal pattern for a single-purpose driver — a `_init()` and one or two helpers.

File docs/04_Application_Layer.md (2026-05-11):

# Application Layer

This document covers the middle of the firmware — the shell, command dispatch, app state, and the core-1 control loop. If you want to add a new shell command or change how the controller behaves, this is the layer you're working in.

The files involved are all in `ADPC_Data_Streaming/`:

| File | Role |
|---|---|
| `adpc_data_streaming.c` | `main()` entry point — almost everything else delegates here |
| `adpc_app.[ch]` | App state struct, line buffer, command dispatch |
| `adpc_app_funcs.[ch]` | Implementations of the individual commands |
| `adpc_core1.[ch]` | The closed-loop current controller (runs on core 1) |

---

## Boot flow

`main()` in `adpc_data_streaming.c` is tiny:

```c
int main() {
    stdio_init_all();           // sets up USB CDC
    char uic;
    scanf(" %c", &uic);         // wait for any character (the handshake)
    printf("[input recieved]\n");
    if(uic == 'q') goto reboot;
    sleep_ms(100);

    while(1) {
        if(app_shell_task(&ui_state) == APP_REBOOT) goto reboot;
    }

reboot:
    printf("\n\nREBOOT!\n");
    reset_usb_boot(0,0);        // re-enumerates as a flash drive
    return 0;
}
```

The `scanf(" %c", &uic)` is a *handshake*. Many serial terminals connect to USB CDC slowly enough that the firmware's early output gets dropped. By waiting for the host to send a byte first, we know the connection is established and our subsequent `printf` will be received.

The host-side `script.py` automatically sends `c\n` as a handshake — operators using a terminal manually just have to press any key.

After the handshake, the main loop just calls `app_shell_task` over and over. Each call processes at most one character of user input.

---

## App state: `ui_state`

```c
typedef struct {
    char ui[UI_BUFF_SIZE];    // line buffer for input
    char ui_cursor;           // how far into the line buffer we are
    float level;              // last commanded differential PWM level
    float current_setpoint;   // last commanded current setpoint (amps)
    bool initialized;         // has `start` or `init` been run?
    bool is_streaming;        // are we currently in rstream / irun stream?
    bool pwm_enabled;         // (informational, not all paths update this)
    bool ph_enabled;          // (informational, not all paths update this)
    bool cl_ictl;             // is core 1 running the closed-loop controller?
    struct ictl_prog current_program;   // the loaded irun program
} app_state_t;

extern volatile app_state_t ui_state;
```

There's one global instance, `ui_state`, declared `volatile` because both cores touch it. The shell passes a pointer to it (`&ui_state`) into every command handler.

A few fields are aspirationally tracked (`pwm_enabled`, `ph_enabled`) — not all paths update them consistently, so don't rely on them as the source of truth for hardware state. The driver-level structs in `mphb2_arr` are more reliable.

### `current_program`

This holds the loaded "current program" — a sequence of setpoints to step through:

```c
struct ictl_prog {
    float timestep;             // milliseconds between setpoints
    float setpoints[ICTL_PROG_MAX_SIZE];
    int N;                       // how many setpoints actually used
    int cycles;                  // (reserved for future use)
};
```

`ICTL_PROG_MAX_SIZE` is 128. The `iprog` shell command populates this struct; `irun` and `irun stream` consume it.

---

## The shell: `app_shell_task`

The shell is a single non-blocking function that the main loop calls repeatedly:

```c
app_result_t app_shell_task(app_state_t *s) {
    // 1. If we're at the start of a line and the buffer still has old data,
    //    print the ">> " prompt and clear the first byte
    if(s->ui_cursor == 0 && s->ui[0] != 0) {
        if(!s->is_streaming) printf(">> ");
        s->ui[0] = 0;
    }
    
    // 2. Try to read one character, with a 1 ms timeout
    int uic = getchar_timeout_us(1000);
    if(uic == PICO_ERROR_TIMEOUT) return APP_RUNNING;
    
    // 3. Backspace handling
    if((char)uic == UI_BACKSPACE) {
        if(s->ui_cursor == 0) return APP_RUNNING;
        printf("\b \b");
        s->ui_cursor -= 1;
        return APP_RUNNING;
    }
    
    // 4. Echo the character back to the user
    if(!s->is_streaming) putchar((char)uic);
    
    // 5. If it's a newline, terminate the buffer and dispatch
    if((char)uic == '\n') {
        s->ui[s->ui_cursor] = 0;
        s->ui_cursor = 0;
        return app_dispatch(s);
    }
    
    // 6. Otherwise, append the character (with overflow guard)
    s->ui[s->ui_cursor] = (char)uic;
    if(s->ui_cursor < UI_BUFF_SIZE - 1) s->ui_cursor++;
    else printf("\b");
    return APP_RUNNING;
}
```

Key points:

- It's non-blocking. Each call either returns `APP_RUNNING` (still building a line) or whatever `app_dispatch` returns.
- The 1 ms timeout makes it safe to call from a busy loop without burning the CPU.
- Echo is suppressed when streaming so that user characters don't corrupt the binary output.
- The buffer is `UI_BUFF_SIZE = 64` bytes. Lines longer than that get truncated (the last character gets a backspace echoed).

---

## Command dispatch: `app_dispatch`

When the shell sees a newline, it calls `app_dispatch`. This is currently implemented as a long sequence of `strncmp` checks:

```c
app_result_t app_dispatch(app_state_t *s) {
    char *ui = s->ui;

    if (s->ui[0] == 'q') return APP_REBOOT;
    if (strncmp(ui, "init", 4) == 0) { ... }
    if (strncmp(ui, "level", 5) == 0) { ... }
    if (strncmp(ui, "isp ", 4) == 0) { app_cmd_isp(s, atof(ui + 4)); }
    if (strncmp(ui, "phen", 4) == 0) { ... }
    if (strncmp(ui, "phd", 3) == 0) { ... }
    if (strncmp(ui, "pwmen", 5) == 0) { ... }
    if (strncmp(ui, "pwmd", 4) == 0) { ... }
    if (strncmp(ui, "start", 5) == 0) { ... }
    if (strncmp(ui, "rstream", 7) == 0) { return app_cmd_rstream(s); }
    if (strncmp(ui, "r0", 2) == 0) { ... }
    if (strncmp(ui, "r1", 2) == 0) { ... }
    if (strncmp(ui, "ictl", 4) == 0) { app_cmd_ictl(s); }
    if (strncmp(ui, "coeff i ", 8) == 0) { ... }
    if (strncmp(ui, "coeff p ", 8) == 0) { ... }
    if (strncmp(ui, "iprog", 5) == 0) { ... }
    if (strncmp(ui, "irun", 4) == 0) { ... }
    if (strncmp(ui, "sdith", 5) == 0) { ... }
    
    printf("%s\n", ui);    // echo unrecognized commands
    return APP_OK;
}
```

This isn't the prettiest dispatch in the world, but it works. There are a few gotchas:

- The checks are **prefix matches** and **not mutually exclusive**. For example, `ictl` would also match a hypothetical `ictlfoo` command. Order matters somewhat.
- After running a command, execution falls through to the next `if` — most commands aren't `return`ed early. This means harmless extra `strncmp` work but is otherwise OK as long as you don't make two prefixes collide.
- The trailing `printf("%s\n", ui)` echoes the command back. This is sometimes redundant (the command itself printed feedback) and sometimes useful (unrecognized commands get echoed so the operator sees they were received but not understood).

### Adding a new shell command

The minimal pattern is:

1. **Write the implementation** in `adpc_app_funcs.[ch]` (or a new file if it's substantial):

   ```c
   // in adpc_app_funcs.h
   app_result_t app_cmd_mything(app_state_t *s, float param);

   // in adpc_app_funcs.c
   app_result_t app_cmd_mything(app_state_t *s, float param) {
       if(!s->initialized) {
           if(!s->is_streaming) printf("Not initialized — run 'start' first\n");
           return APP_ERROR;
       }
       // ... do the thing ...
       if(!s->is_streaming) printf("[did the thing with param = %.2f]\n", param);
       return APP_OK;
   }
   ```

2. **Add the dispatch** in `app_dispatch`:

   ```c
   if(strncmp(ui, "mything ", 8) == 0) {
       return app_cmd_mything(s, atof(ui + 8));
   }
   ```

3. **Document it** in `HOW_TO_ADPC_Streaming.md`.

The "non-blocking" model means your command handler is allowed to spend time — block, loop, talk to hardware. The shell will pick up new input on the next call to `app_shell_task` *after* yours returns. If your command takes more than a fraction of a second, it should poll for user input itself (the way `app_cmd_irun` does) so the user can abort.

---

## Command catalog

A summary of what each existing command does and where its implementation lives. For operator-level usage details, see `HOW_TO_ADPC_Streaming.md`.

| Command | Implementation | Notes |
|---|---|---|
| `start` | `app_dispatch` (inline) | Calls `adpc_init`, enables PWM and PH_EN |
| `init` | `adpc_init` in `adpc_app_funcs.c` | Lower-level init; doesn't enable PH_EN |
| `level <n>` | `app_dispatch` (inline) | Open-loop set differential PWM level |
| `phen` / `phd` | `app_dispatch` (inline) | Phase-enable gate |
| `pwmen` / `pwmd` | `app_dispatch` (inline) | PWM peripheral on/off, sets level to 0 |
| `sdith <f>` | `app_dispatch` (inline) | Spatial-dithering level set |
| `isp <amps>` | `app_cmd_isp` | Set current setpoint for closed-loop |
| `ictl` | `app_cmd_ictl` | Start or stop the core-1 controller |
| `coeff i <f>` / `coeff p <f>` | `app_dispatch` (inline) | Tune PI coefficients live |
| `iprog` | `app_dispatch` (inline) | Interactive program entry |
| `irun` | `app_cmd_irun` | Run loaded program |
| `irun stream` | `app_cmd_irun_streaming` | Run loaded program with simultaneous streaming |
| `rstream` | `app_cmd_rstream` | Stream raw ADC data |
| `r0 <n>` / `r1 <n>` | `app_dispatch` (inline) | Print N samples from the DMA buffers for inspection |
| `q` | `app_dispatch` (returns `APP_REBOOT`) | Reboot to flash mode |

---

## The core-1 controller (`adpc_core1.c`)

When `ictl` is invoked, core 1 is launched and starts running `core1_ictl()`. This is the closed-loop current controller. It:

1. Polls the DMA write position on ADC 0 (the 16-bit ISNS ADC).
2. When a new sample arrives, computes a 5-sample moving average.
3. Subtracts the setpoint to get an error.
4. Runs a PI law (proportional + integral with anti-windup clamps).
5. Writes the new level to the H-bridges using `mphb_set_dlevel_all_spatial_dithering`.
6. Checks the inter-core FIFO for a stop request.

### The control state

```c
typedef struct {
    float accum;     // integrator state
    float i_coeff;   // integral gain
    float p_coeff;   // proportional gain
} ictl_info_t;

extern volatile ictl_info_t ictlInfo;
```

This is global, declared `volatile` so that the shell on core 0 can update `i_coeff` and `p_coeff` live via the `coeff i` and `coeff p` commands and core 1 will see the changes.

### The control law

```c
float err = (avg - ictl_sp);
float incr = err * ictlInfo.i_coeff;
ictlInfo.accum += incr;
if (ictlInfo.accum < -50000) ictlInfo.accum = -50000;
if (ictlInfo.accum > 5000)   ictlInfo.accum = 5000;

float level = (ictlInfo.accum + ictlInfo.p_coeff * err) / 100000;
if(level >  0.3) level =  0.3;
if(level < -0.3) level = -0.3;
ui_state.level = level;
mphb_set_dlevel_all_spatial_dithering(ui_state.level);
```

The setpoint `ictl_sp` is computed from `ui_state.current_setpoint` using the same hand-calibrated scaling as `app_cmd_isp`. Both the integrator (`accum`) and the output (`level`) are clamped — the integrator asymmetrically because the system can only push current one way effectively (positive heating current; negative is impractical for the heater load), and the output to ±0.3 to keep things safe.

### Inter-core handshake

```c
if(multicore_fifo_rvalid()) {
    int cmd = multicore_fifo_pop_blocking_inline();
    if(cmd == MC_FIFO_STOP_FLAG) break;
}
// ... after the loop:
ui_state.cl_ictl = false;
if(!ui_state.is_streaming) printf("Exiting core 1.\n");
multicore_fifo_push_blocking(1);   // ack to core 0
```

Core 0 (via `app_cmd_ictl`) pushes `MC_FIFO_STOP_FLAG` into the FIFO, then waits for an ack, then calls `multicore_reset_core1()`. This is the *only* clean way to stop core 1.

`MC_FIFO_STOP_FLAG` is `0xBEEF` — chosen to be distinguishable from any sample value you'd reasonably get in the FIFO. If you start using the FIFO for actual data, pick a sentinel that can't collide with valid data values, or use multiple words (e.g. a command word + a payload word).

### Modifying the controller

The control law itself is one screen of code in `core1_ictl()`. To change it (e.g. add a derivative term, change the filter, use a different ADC channel), edit that function directly. Don't worry about backwards compatibility — there are no consumers of the controller's internal state outside core 1.

A few sane patterns when you do this:

- **Print sparingly.** The default code prints `ERR / INCR / ACC / LVL` once every 128 samples. More frequent prints will starve the USB pipe.
- **Always guard prints with `if(!ui_state.is_streaming)`** so they don't corrupt streaming output.
- **Re-clamp the integrator** if you change anything about the gain. Old clamps may no longer be appropriate.
- **Watch for divisions and casts.** The existing code mixes `float`, `int32_t`, and integer divisions — easy to introduce truncation errors.

---

## How `irun` works under the hood

It's instructive to read `app_cmd_irun` end-to-end because it's a representative example of a complex command:

```c
app_result_t app_cmd_irun(app_state_t *s) {
    mphb_set_ph_en_all(true);                       // turn outputs on
    if(!ui_state.cl_ictl) {                         // ensure controller running
        if(app_cmd_ictl(s) != APP_OK) return APP_ERROR;
    }
    uint64_t ts = (int)(s->current_program.timestep * 1000);   // µs
    uint64_t t = time_us_64();
    bool ui_break = false;
    for(int i = 0; i < s->current_program.N; i++) {
        while(time_us_64() - t <= ts) {
            if(stdio_getchar_timeout_us(10) != PICO_ERROR_TIMEOUT) {
                ui_break = true;
                break;
            }
        }
        t += ts;                                    // advance, don't drift
        if(ui_break) break;
        if(app_cmd_isp(s, s->current_program.setpoints[i]) != APP_OK) break;
    }
    app_cmd_ictl(s);                                // stop the controller
    mphb_set_ph_en_all(false);                      // turn outputs off
    return APP_OK;
}
```

Notice:

- It enables `PH_EN` before doing anything else (and disables it on exit). The controller has authority over the level, but `irun` owns the on/off.
- It launches core 1 if not already running, and tears it down on exit.
- The timing loop uses `t += ts` (not `t = now`) to avoid drift. If your command takes 50 µs longer than expected on one iteration, the next iteration is 50 µs shorter — total time stays correct.
- It polls for any user input as an abort signal. This is the standard pattern for blocking commands.

The streaming variant (`app_cmd_irun_streaming`) interleaves USB CDC writes with the program-stepping loop. See [`05_DMA_PIO_Streaming.md`](05_DMA_PIO_Streaming.md) for the streaming details.

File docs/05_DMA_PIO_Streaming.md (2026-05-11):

# DMA, PIO & Streaming — A Deep Dive

This document explains how the firmware moves ADC samples from chip to memory and from memory to USB, without bogging down the CPU. **Read this before adding any new high-speed data source** (such as the mass spec interface's ADC).

The same pattern — PIO triggers, DMA into a ping-pong ring buffer, IRQ-updated globals, polling consumers — will work just as well for the MSIF's analog inputs and for any future high-rate UART data. So while the examples here are about the MCP ADCs, treat it as a template.

---

## Why not just read the ADCs in a loop?

The MCP3462R, configured with OSR=2048 and a 15 MHz master clock, produces a new conversion every few microseconds. The 24-bit ADC at OSR=512 is even faster. If we tried to poll-read each conversion from main code:

- We'd need ~5 µs of SPI traffic per sample, all CPU.
- We'd miss samples whenever any other code ran (USB tick, anything else).
- We couldn't simultaneously do anything else at sample rate.

DMA + PIO solves all three: the hardware reads samples on its own, deposits them in RAM, and only interrupts the CPU when an entire batch is done.

---

## The pipeline, end-to-end

```
                    ADPC board                          PGA2350 (RP2350)
                ┌──────────────────┐         ┌──────────────────────────────┐
                │   MCP3462R ADC   │         │                              │
                │                  │  nIRQ   │  PIO state machine           │
   sample ─────►│  (continuous     │ ─────► │  (mcp_pio.pio assembly)      │
                │   conversion)    │         │                              │
                │                  │  SCK    │  shifts 32 bits in           │
                │                  │ ◄────── │                              │
                │                  │  MISO   │                              │
                │                  │ ─────► │                              │
                └──────────────────┘         │              │                │
                                             │              │ RX FIFO        │
                                             │              ▼                │
                                             │       DMA channel A           │
                                             │       (or B, ping-pong)       │
                                             │              │                │
                                             │              │ written to RAM │
                                             │              ▼                │
                                             │   ┌──────────────────────┐   │
                                             │   │  dma_buff_adc_0[]    │   │
                                             │   │   ┌──────┬──────┐    │   │
                                             │   │   │  A   │  B   │    │   │
                                             │   │   └──────┴──────┘    │   │
                                             │   │   ↑ aligned,         │   │
                                             │   │     ring-mode wraps  │   │
                                             │   └──────────────────────┘   │
                                             │              │                │
                                             │              │ IRQ when half  │
                                             │              ▼ is full        │
                                             │  dma_irq_handler_0()          │
                                             │   - clears IRQ flag           │
                                             │   - updates                   │
                                             │     dma0_last_written         │
                                             │              │                │
                                             │              ▼                │
                                             │  Consumer (core 0 streaming   │
                                             │  or core 1 control loop)      │
                                             └──────────────────────────────┘
```

---

## The PIO program

PIO ("Programmable I/O") is a small bit-banged state machine — almost like a tiny coprocessor — that can drive GPIO pins in patterns more complex than dedicated peripherals. The RP2350 has 3 PIO blocks (this firmware uses 2: `pio0` and `pio1`), each with 4 state machines, each running its own little program.

The MCP-read PIO program is in `mcp_pio.pio`:

```
.program mcp_conversions_read
.side_set 1                                ; the SCK pin

.wrap_target
public entry_point:
    set x, 31           side 0             ; we want 32 bits
    wait 1 jmppin       side 0             ; wait for nIRQ to go high (idle)
    wait 0 jmppin       side 0 [1]         ; wait for nIRQ to go low (data ready)
bitloop:
    nop                 side 1 [1]         ; SCK high
    in  pins, 1         side 0             ; SCK low, sample MISO into ISR
    jmp x-- bitloop     side 0
.wrap                                       ; back to entry_point
```

What this does, in human terms:

1. Wait for the nIRQ pin to be high *first* (so we don't trigger on stale low).
2. Wait for nIRQ to go low (the ADC's "data ready" signal).
3. Generate 32 clock cycles on SCK, sampling MISO on each falling edge.
4. The 32 bits get pushed into the PIO's RX FIFO automatically (because of `set_in_shift(..., autopush=true, 32)` set up in `mcp_pio.c`).
5. Loop back to step 1.

The state machine just keeps doing this forever. Each push into the RX FIFO triggers a DREQ ("data request") to the DMA, which then copies the FIFO contents into RAM.

### Notes on PIO

- Each state machine has 4 instruction slots... wait, no, 32 (4×8 = 32 total per PIO block; the program shown above uses 6). State machines on the same PIO block share the instruction memory.
- The `.side_set 1` directive means "one bit of side-set," used here to drive SCK as a side-effect of each instruction.
- `jmppin` and the `wait jmppin` syntax refer to a pin chosen at runtime by `sm_config_set_jmp_pin` — this is how the program knows which physical pin is nIRQ.
- Clock divider: `sm_config_set_clkdiv(&c, 125)` gives a 1 MHz state machine clock on a 125 MHz system clock. With the `[1]` delays in the SCK loop, this produces roughly 250 kHz SCK on the ADC.

---

## Ping-pong DMA

A single DMA channel can be set to do a fixed number of transfers, then stop. If you want continuous capture, you need *two* channels that take turns. This is called *ping-pong* DMA.

In `mcp_pio_init`:

```c
uint dma_a = dma_claim_unused_channel(true);
uint dma_b = dma_claim_unused_channel(true);

// Channel A
channel_config_set_dreq(&cfg_a, pio_get_dreq(pio, sm, false));
channel_config_set_chain_to(&cfg_a, dma_b);      // ← when I finish, start B
channel_config_set_ring(&cfg_a, 1, dma_buff_alignment_bytes);
dma_channel_configure(dma_a, &cfg_a,
    sample_buff,                 // ← write starts at base
    &pio->rxf[sm],               // ← read from the PIO RX FIFO
    DMA_BUFF_SIZE, false);

// Channel B
channel_config_set_chain_to(&cfg_b, dma_a);      // ← when I finish, start A
channel_config_set_ring(&cfg_b, 1, dma_buff_alignment_bytes);
dma_channel_configure(dma_b, &cfg_b,
    sample_buff + DMA_BUFF_SIZE, // ← write starts at base + half
    &pio->rxf[sm],
    DMA_BUFF_SIZE, false);
```

A finishes, automatically triggers B; B finishes, automatically triggers A. The DMA hardware does this without CPU intervention.

**Ring mode** (`channel_config_set_ring`) is the magic that makes this efficient. It tells the DMA "wrap the write address back to a power-of-two-aligned base when its lower bits would overflow." Combined with the `__attribute__((aligned(...)))` on the buffer, this means we don't need to *reset* the write address between transfers — the hardware wraps automatically.

The alignment math:
```c
const uint32_t dma_buff_alignment_bytes = 31 - __builtin_clz(DMA_BUFF_SIZE*sizeof(uint32_t));
```
`__builtin_clz` is "count leading zeros" — for `DMA_BUFF_SIZE = 128` words × 4 bytes = 512 bytes, this returns `9` (since 512 = 2^9). The DMA ring config wants the *log2* of the wrap region. So each DMA channel's write pointer wraps every 512 bytes — i.e. fills its half, then restarts at the half's base.

The buffer declaration:
```c
volatile uint32_t dma_buff_adc_0[DMA_BUFF_SIZE * 2]
    __attribute__((aligned(DMA_BUFF_SIZE * sizeof(uint32_t))));
```
The `aligned` attribute ensures the array starts at a 512-byte boundary, which is necessary for the ring wraparound to work correctly.

---

## The IRQ handler

When a DMA channel finishes a transfer, it raises an IRQ on its assigned line (`DMA_IRQ_0` for ADC 0, `DMA_IRQ_1` for ADC 1). The handler:

```c
void dma_irq_handler_0(void) {
    int culprit_is_a = dma_hw->ints0 & (1u << mpio_0.dma_a);
    if (culprit_is_a) {
        dma_hw->ints0 = 0x1 << (mpio_0.dma_a);   // clear flag for A
        dma0_last_written = 1;
    } else {
        dma_hw->ints0 = 0x1 << (mpio_0.dma_b);   // clear flag for B
        dma0_last_written = 2;
    }
}
```

Three jobs only:

1. Figure out which of the two channels caused the IRQ.
2. Clear the IRQ flag (write `1` to the corresponding bit — yes, you clear by writing `1`).
3. Update `dma0_last_written` so consumers know what's new.

**That's it.** Anything else in this function will hurt the system. There was originally a sample-post-processing loop in the handler (right-shift every sample by 16 bits) — it's now commented out because post-processing belongs in the consumer.

---

## Reading from the DMA buffer

Two patterns are used in the codebase.

### Pattern 1: batch-at-a-time (used by `app_cmd_rstream`)

Wait for a half-buffer to fill, then ship the whole thing:

```c
int dma0_last_printed = dma0_last_written;

while(streaming) {
    // wait for new batch
    while(dma0_last_written == dma0_last_printed) {
        // poll for user input, service USB, etc.
    }

    // ship the half that just got written
    tud_cdc_write(mpio_0.buff + (dma0_last_written - 1) * DMA_BUFF_SIZE,
                  DMA_BUFF_SIZE * sizeof(uint32_t));
    tud_cdc_write_flush();
    dma0_last_printed = dma0_last_written;
}
```

Note the indexing: `dma0_last_written` is `1` if A finished (so we read the lower half, starting at index 0) or `2` if B finished (read the upper half, starting at index `DMA_BUFF_SIZE`). The expression `(dma0_last_written - 1) * DMA_BUFF_SIZE` evaluates to `0` or `DMA_BUFF_SIZE` accordingly.

This pattern is **easy** and **efficient** — you wake up only twice per full buffer cycle, you grab a contiguous block of memory, you ship it. Use it for streaming-style consumers where latency at the half-buffer level is fine.

### Pattern 2: sample-at-a-time (used by `core1_ictl`)

The control loop needs to react as quickly as possible — at the sample level, not at the buffer level. So instead of waiting for a half-buffer, we poll the DMA's *internal* counter:

```c
uint dma_ch_writing = (dma0_last_written == 2) ? mpio_0.dma_a : mpio_0.dma_b;
uint index_old = 0;

while(1) {
    // wait for either the buffer to flip OR for the current write index to advance
    while (lw_current == dma0_last_written &&
           (DMA_BUFF_SIZE - dma_channel_hw_addr(dma_ch_writing)->transfer_count) == index_old) {
        tight_loop_contents();
    }
    
    if(lw_current != dma0_last_written) goto start;   // buffer flipped — re-sync
    
    // process the sample at index_old (with averaging window, etc.)
    int *base = (int *)mpio_0.buff;
    int  current_buf_base = (2 - lw_current) * DMA_BUFF_SIZE;
    int  current_index    = current_buf_base + (DMA_BUFF_SIZE - dma_channel_hw_addr(dma_ch_writing)->transfer_count - 1);
    float avg = 0;
    for(int i = 0; i < 5; i++) {
        avg += base[(current_index - i) & (2*DMA_BUFF_SIZE - 1)];
    }
    avg /= 5;
    
    // ... control law ...
    
    index_old = (index_old + 1) % DMA_BUFF_SIZE;
}
```

A few subtleties:

- `dma_channel_hw_addr(ch)->transfer_count` is the *remaining* count, decremented each time DMA writes. So `DMA_BUFF_SIZE - transfer_count` is how many samples have been *written into the current half*.
- Indexing back through the window uses bitmask wrap: `& (2*DMA_BUFF_SIZE - 1)` works because the total buffer is power-of-two-sized.
- The `goto start` retries the whole setup when the buffer flips. This is the standard escape hatch when the data stops being consistent under your feet.

Use this pattern when you need per-sample latency. Use Pattern 1 otherwise.

---

## USB CDC streaming

When we want to fire ADC bytes at the host, the standard pattern is:

```c
stdio_set_driver_enabled(&stdio_usb, false);   // mute printf

// ... main streaming loop ...
// (per-half-buffer)
bsent += tud_cdc_write(mpio_0.buff + (dma0_last_written - 1) * DMA_BUFF_SIZE,
                       DMA_BUFF_SIZE * sizeof(uint32_t));
tud_cdc_write_flush();
while (tud_cdc_write_available() < CFG_TUD_CDC_TX_BUFSIZE) tud_task();

// ... at end ...
stdio_set_driver_enabled(&stdio_usb, true);    // restore printf
```

Key things to know:

1. **Mute stdio first.** Otherwise random `printf` calls from anywhere (including deep in driver code) will interleave with your binary data and the host parser will get confused.
2. **CFG_TUD_CDC_TX_BUFSIZE** is `512` (set in `CMakeLists.txt`). This is the size of the USB driver's internal buffer.
3. **`tud_cdc_write` may return less than you asked for** if the internal buffer is fuller than what's requested. You must check the return and re-send the remainder, or do what the existing code does: wait for the buffer to drain before continuing.
4. **`tud_task()` must be called periodically** during streaming to actually move bytes out over USB. The `while (... < CFG_TUD_CDC_TX_BUFSIZE) tud_task();` line does this.
5. **Restore stdio** when you're done, or future `printf` calls won't reach the host.

The host side (`script.py`) reads raw bytes and watches for the literal string `"END RAW DATA STREAM"` to know when the stream stops. The firmware emits this string *after* re-enabling stdio. Anything else printed during streaming time is corrupted data.

---

## How to extend this pattern to a new data source

Here's a checklist for adding a new high-speed data source — say, a second ADC over a custom protocol, or the mass spec's data stream coming over UART.

### 1. Decide on the trigger mechanism

You need *something* to indicate "a new sample is ready." Options:

- **A pin going low** (like nIRQ here) — best for SPI/I2C ADCs. Drive a PIO state machine with the pin as the `jmppin`.
- **A UART RX byte arriving** — UART hardware already has a DREQ. Just point a DMA channel at the UART RX FIFO with the UART DREQ as the trigger.
- **A timer expiring** — use a PWM slice with `pwm_get_dreq()` for the DREQ. Cheap and exact.
- **Software-paced** — write to a small register that has a configurable DREQ. Rarely needed.

### 2. Set up the DMA channels

Two ping-pong channels chained to each other, each pointing at a half of an aligned buffer:

```c
#define MY_DMA_BUFF_SIZE 64   // pick a power of 2

volatile uint32_t my_buff[MY_DMA_BUFF_SIZE * 2]
    __attribute__((aligned(MY_DMA_BUFF_SIZE * sizeof(uint32_t))));

uint dma_a = dma_claim_unused_channel(true);
uint dma_b = dma_claim_unused_channel(true);

const uint32_t alignment_bytes = 31 - __builtin_clz(MY_DMA_BUFF_SIZE * sizeof(uint32_t));

dma_channel_config cfg_a = dma_channel_get_default_config(dma_a);
channel_config_set_transfer_data_size(&cfg_a, DMA_SIZE_32);   // or 16 or 8, as appropriate
channel_config_set_read_increment(&cfg_a, false);             // FIFO doesn't advance
channel_config_set_write_increment(&cfg_a, true);             // RAM does
channel_config_set_ring(&cfg_a, 1, alignment_bytes);          // ring-mode wraparound
channel_config_set_dreq(&cfg_a, MY_DREQ);                     // ← your trigger source
channel_config_set_chain_to(&cfg_a, dma_b);
dma_channel_configure(dma_a, &cfg_a, my_buff, MY_FIFO_ADDR, MY_DMA_BUFF_SIZE, false);

// (mirror image for dma_b, pointing at my_buff + MY_DMA_BUFF_SIZE)
```

### 3. Pick an IRQ line

The RP2350 has two DMA IRQ lines (`DMA_IRQ_0` and `DMA_IRQ_1`). In this firmware:
- `DMA_IRQ_0` is used by ADC 0 (16-bit ISNS).
- `DMA_IRQ_1` is used by ADC 1 (24-bit TSNS/VSNS).

If you want to handle your new DMAs separately, you need a third line — which means you'll have to share a line and dispatch in the handler based on which channel raised the flag. The existing handlers in `adpc_app_funcs.c` show the pattern: check `dma_hw->ints0` against each channel's bit position.

### 4. Write your IRQ handler

Three jobs again:

```c
void my_dma_handler(void) {
    int culprit_is_a = dma_hw->ints0 & (1u << my_dma_a);
    if (culprit_is_a) {
        dma_hw->ints0 = 0x1 << my_dma_a;
        my_last_written = 1;
    } else {
        dma_hw->ints0 = 0x1 << my_dma_b;
        my_last_written = 2;
    }
}
```

Keep it short. Don't do post-processing here.

### 5. Hook up the IRQ

```c
irq_set_exclusive_handler(DMA_IRQ_0, my_dma_handler);
dma_channel_set_irq0_enabled(my_dma_a, true);
dma_channel_set_irq0_enabled(my_dma_b, true);
irq_set_enabled(DMA_IRQ_0, true);
```

If you're *sharing* the IRQ line with existing handlers, use `irq_add_shared_handler` instead and accept the small overhead.

### 6. Consume the data

Pick Pattern 1 or 2 from above depending on whether you want batch-at-a-time or sample-at-a-time.

### 7. Add a shell command

Plumb it into `app_dispatch` and `adpc_app_funcs.c` following the conventions in [`04_Application_Layer.md`](04_Application_Layer.md).

---

## Diagnostics

When data acquisition isn't working, the typical questions and how to answer them:

| Question | How to check |
|---|---|
| Is the ADC even running? | `gpio_get(nirq_pin)` should be toggling. If always high, the ADC isn't pulling it low — likely a config problem or missing pull-up. |
| Is the PIO consuming the FIFO? | Look at `pio->fstat` for the relevant SM — should see RX FIFO neither full nor empty most of the time. If consistently full, the DMA isn't draining it. |
| Is the DMA running? | `dma_channel_hw_addr(ch)->transfer_count` should be counting down. If it's stuck, the DMA isn't getting DREQs. |
| Are the IRQs firing? | Toggle a GPIO inside the IRQ handler and look at it on a scope. |
| Is the consumer seeing fresh data? | Print `dma0_last_written` from main and watch it alternate 1 → 2 → 1 → 2. |
| Are the values plausible? | Use `r0` or `r1` shell commands to dump the last few raw samples to the terminal. Decode by hand against the chip datasheet. |

A trick the firmware uses: in `core1_ictl`, the line
```c
sio_hw->gpio_hi_togl |= (1U << (ADPC_PIN_LED - 32));
```
toggles the on-board LED at the sample rate. A square wave on the scope (or on the LED if you can see it flickering predictably) confirms the loop is running at the expected frequency.

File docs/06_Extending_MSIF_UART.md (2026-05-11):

# Extending the System: MSIF + UART

The biggest open work item is the **MSIF firmware** — the code that runs on the Mass Spec Interface board and connects to the Balzers QMS-112 mass spectrometer. The MSIF board exists in hardware (see `Hardware/Documentation/ADPC & MSIF Schematics/`), the firmware skeleton is in `MSIF_dev/`, and there's a friendly getting-started document by Maxim for whoever picks this up (`MSIF_dev/MSIF_Docs/isaiah_getting_started.md`). Read that first — it covers basic Pico SDK setup, getting code building, and a starting point for digital I/O.

This document focuses on the **architectural decisions** that come *after* you have basic GPIO working: how to add UART communication between the ADPC and the MSIF, and how to set up DAQ (data acquisition) on the MSIF side that fits the existing patterns.

---

## What the MSIF needs to do

In rough priority order:

1. **Read QMS digital outputs** (`EMIS_OK`, etc.) into RP2350 GPIO inputs. — *Easy. Start here.*
2. **Drive QMS digital inputs** (handshake lines back to the QMS) from RP2350 GPIO outputs. — *Also easy.*
3. **Read QMS analog outputs** (FMASS+, etc.) via an ADC. — *Medium. Looks a lot like the ADPC's TSNS channel.*
4. **Drive QMS analog inputs** with a DAC. — *Medium. New driver work, but conceptually similar to PWM.*
5. **Translate high-level commands** ("set mass to X", "scan from A to B") into the right sequence of analog/digital actions. — *The interesting part.*
6. **Communicate with the ADPC over UART** for coordinated experiments. — *Once 1–5 are working, this glues it all together.*
7. **Stream mass spec data** to the host (or to the ADPC) for logging. — *Once 6 is working.*

The first four items are mostly straightforward hardware-driver work, similar in shape to what's in `ADPC_Dev/`. The architectural decisions are in items 6 and 7.

---

## UART between the ADPC and MSIF

### Pin choice

Looking at `ADPC_Dev/ADPC_Docs/MCU Pinout.md`, GPIO 33 and 34 on the ADPC's PGA2350 are reserved for `UART_RX` and `UART_TX` respectively. These pins are routed through the hardware to the MSIF connector. On the MSIF side, find the matching pair in the MSIF schematic — they should be similarly placed on its PGA2350.

Define them in both boards' config headers:

```c
// in ADPC_Dev/ADPC_cfg.h:
#define ADPC_MSIF_UART       uart0
#define ADPC_MSIF_UART_TX    34
#define ADPC_MSIF_UART_RX    33
#define ADPC_MSIF_UART_BAUD  115200    // start conservative; raise later if needed

// in MSIF_dev/MSIF_cfg.h:
#define MSIF_ADPC_UART       uart0
#define MSIF_ADPC_UART_TX    <pin>
#define MSIF_ADPC_UART_RX    <pin>
#define MSIF_ADPC_UART_BAUD  115200
```

### Driver structure

Mirror the existing driver structure. Create a folder `MSIF_dev/adpc_uart_driver/` (or `ADPC_Dev/adpc_msif_uart.[ch]` for the ADPC side) with:

- A struct that holds the UART instance and any state needed.
- An `_init()` function.
- Read/write functions, at minimum a blocking pair.
- Hazards documented in a `README.md`.

A minimal skeleton:

```c
// adpc_msif_uart.h
typedef struct {
    uart_inst_t *uart;
    uint baud;
    bool initialized;
} adpc_msif_uart_t;

void adpc_msif_uart_init(adpc_msif_uart_t *u, uart_inst_t *uart,
                         int tx_pin, int rx_pin, uint baud);
int  adpc_msif_uart_write(adpc_msif_uart_t *u, const uint8_t *data, size_t len);
int  adpc_msif_uart_read (adpc_msif_uart_t *u,       uint8_t *dst,  size_t len, uint timeout_ms);
```

Initialization is plain Pico SDK:

```c
void adpc_msif_uart_init(adpc_msif_uart_t *u, uart_inst_t *uart,
                         int tx_pin, int rx_pin, uint baud) {
    u->uart = uart;
    u->baud = uart_init(uart, baud);
    gpio_set_function(tx_pin, GPIO_FUNC_UART);
    gpio_set_function(rx_pin, GPIO_FUNC_UART);
    uart_set_format(uart, 8, 1, UART_PARITY_NONE);     // 8N1
    uart_set_fifo_enabled(uart, true);
    u->initialized = true;
}
```

### Protocol design

Don't try to send floating-point setpoints as raw text — that's slow to parse and error-prone. Use a small framed binary protocol. A sketch:

```
  [STX] [TYPE] [LENGTH] [PAYLOAD...] [CRC16]
   1B    1B     1B        0–252B       2B
```

- `STX` is a fixed byte (e.g. `0xA5`). If the receiver sees anything else, it discards and resyncs.
- `TYPE` indicates the message: setpoint command, status update, data sample, etc.
- `LENGTH` is the payload length, capped at something reasonable.
- `CRC16` checks integrity. A bad CRC means drop the frame and resync to the next `STX`.

Message types you'll want roughly:

| Direction | Type | Payload | Purpose |
|---|---|---|---|
| ADPC → MSIF | `0x10` SET_MASS | float | Set QMS mass target |
| ADPC → MSIF | `0x11` START_SCAN | float start, float end, float speed | Start a mass scan |
| ADPC → MSIF | `0x12` STOP_SCAN | (none) | Halt the scan |
| MSIF → ADPC | `0x20` SCAN_SAMPLE | float mass, int32 intensity | One data point |
| MSIF → ADPC | `0x21` STATUS | uint8 flags | EMIS_OK, etc. |
| Either | `0x00` PING | (none) | Heartbeat |

The point isn't to lock this design in — it's that **you need to design it before you write either side**. Document it (in a markdown file alongside the driver) so the two ends agree.

### Receive in interrupt or by DMA?

Three patterns:

1. **Polling** — call `uart_is_readable()` in your main loop and read bytes one at a time. Simple, works fine if your main loop is fast and you don't care about losing a few bytes during long operations. Try this first.
2. **UART RX IRQ** — register a handler that fires whenever bytes arrive, accumulate into a ring buffer. Better latency, won't drop bytes during slow operations. More complex.
3. **DMA on UART RX** — point a DMA channel at the UART RX FIFO with `uart_get_dreq()` as the DREQ. Bulletproof, never drops bytes, but only worth it for high-rate data (think: streaming sample data at >1 Mbps).

For the command-channel UART, start with polling. If you have a problem with dropped commands, move to IRQ. DMA on UART is overkill for ~115 kbps command traffic.

For *streaming sample data* over UART (if you decide to send mass spec samples from MSIF to ADPC at high rate), DMA is the right answer — see the section below.

---

## DAQ on the MSIF side

The MSIF will have its own ADC(s) reading QMS analog outputs. The pattern from the ADPC carries over directly: SPI-or-similar ADC, PIO machine to capture conversions, ping-pong DMA into RAM, IRQ updates a `volatile int` that consumers poll.

### If the MSIF uses an MCP3x6xR-family ADC

Lucky you — the entire driver in `mcp3x6xR_driver/` (both `mcp3x6xR.[ch]` and `mcp_pio.[ch]`) can be **copied verbatim** into `MSIF_dev/`. Update the `#include` paths, add the source files to `MSIF_dev/CMakeLists.txt`, and you're 90% of the way there.

The one thing to **double-check** is the PIO state machine count. `mcp_pio_init` is hardcoded to claim `pio0` and `pio1` based on a call counter, with a panic if you try to call it a third time. Since the MSIF is a *separate* RP2350 from the ADPC, it has its own PIO blocks — so the third-call panic doesn't apply across boards. But if you want both an MCP-style ADC *and* some other PIO-based peripheral on the MSIF, you'll need to do the bookkeeping yourself.

### If the MSIF uses a different ADC

You'll need to write a new driver. The structure should mirror `mcp3x6xR_driver/`:

```
MSIF_dev/my_adc_driver/
├── my_adc.h         # register defines, struct types, function prototypes
├── my_adc.c         # SPI-level configuration code
├── my_adc_pio.pio   # PIO program for streaming reads (if applicable)
├── my_adc_pio.h     # PIO state machine setup
├── my_adc_pio.c     # PIO + DMA setup, very similar to mcp_pio.c
└── README.md        # what this driver does, hazards, etc.
```

Use `mcp3x6xR_driver/` as your template. The structure of `mcp_pio.c` in particular is a good guide for any "PIO triggered by an external IRQ pin, results DMA'd into a ring buffer" peripheral.

### Sampling the analog inputs

The QMS-112 analog outputs (FMASS+, etc.) come into the MSIF via op-amp front-ends. The MSIF's ADC reads them on different channels of the same chip — exactly the way the ADPC's 24-bit ADC reads multiple channels in scan mode. Configure the ADC in scan mode and the channel ID will be encoded in the upper bits of each sample word, just like ADC 1 on the ADPC.

```c
// Example: MSIF ADC config for two channels in scan mode
cfg.input_mode = MCP_SCAN_MODE;
cfg.scan_sel = MCP_SCAN_SEL_BIT_DIFF_A | MCP_SCAN_SEL_BIT_DIFF_B;
cfg.cfgs[3] = MCP_CFG3_CONV_MODE_CONTINUOUS | MCP5_CFG3_DATA_FORMAT_32_CHID_SGN4_24;
```

In the consumer, unpack each word with the helpers from the host-side `script.py`:
```python
chid = (word >> 28) & 0xF
val  = sign_extend_24(word & 0xFFFFFF)
```
(C versions of these decode operations belong in a new `MSIF_dev/msif_adc_decode.[ch]` file — the host code is python, that's a python implementation of the same.)

---

## Streaming MSIF data over UART to the ADPC

If you want the MSIF to stream sample data to the ADPC at high rate, the cleanest design is:

```
MSIF                                                    ADPC
────                                                    ────

  ADC samples ─► PIO ─► DMA(ring buf)                     UART RX FIFO
                              │                                  ▲
                              │                                  │
                       IRQ handler updates                       │
                       msif_last_written                         │
                              │                                  │
                              ▼                                  │
                       Main loop:                                │
                       grab newest half-buffer                   │
                       frame it (STX + TYPE + LEN + DATA + CRC) ─┘
                              │
                       uart_write_blocking()
                              or
                       DMA from buffer to UART TX FIFO
                              (using uart_get_dreq for the DREQ)
```

On the ADPC side, a *receive*-DMA pattern complements this:

- Point a DMA channel at the UART RX FIFO with the RX DREQ.
- Use ping-pong, same as for the ADCs.
- IRQ on half-buffer-full sets a flag the main loop polls.

This effectively gives you a "wireless ADC" — the MSIF's ADC, exposed to the ADPC's firmware as if it were a third local ADC. The data ends up in the same DMA-style ring buffer the ADPC firmware already knows how to consume and stream.

If you build this, the ADPC's existing `rstream` command can be extended to stream the MSIF data alongside the ADPC's own data — interleaving the buffers from ADC 0, ADC 1, and "UART ADC" all on the USB output. The host-side decoder already separates channels by their channel-ID bits; you'd add a sentinel byte or a separate channel-ID range for the MSIF data so the decoder knows which board it came from.

---

## A reasonable order of work

For the developer picking up MSIF:

1. **Get basic firmware running.** Build, flash, blink LED, USB CDC echo. *(One day.)*
2. **Wire up the digital I/O.** Read EMIS_OK and friends, drive QMS digital inputs. Add to `msif_gpio.c`. *(A few days.)*
3. **Add UART to the ADPC.** Stub out a frame format. Send PING from the ADPC, blink the LED on receipt. Confirm round-trip. *(A few days.)*
4. **Pick an ADC for the MSIF.** If MCP-family, you're nearly done — copy the driver, instantiate it on the right SPI bus. If not, write a driver following the pattern. *(One to two weeks.)*
5. **Pick a DAC.** Similar story — likely an SPI DAC with its own driver. *(A week.)*
6. **Implement the high-level QMS commands.** Each high-level command becomes a function that orchestrates DAC writes and digital outputs in the right sequence. *(One to two weeks.)*
7. **Streaming.** UART-streaming mass spec samples to the ADPC, then on to the host. *(One week.)*

Total realistic estimate: 4–8 weeks for someone moderately comfortable with C, longer otherwise.

---

## What to put in the existing patterns vs. what to redesign

A note on temptation: when you're picking up a new codebase, there's an urge to clean things up, modularize, rewrite. **Resist this urge for the first month.** The reasons:

- The existing patterns work and have been debugged through real hardware bring-up. Subtle pitfalls (the DMA buffer indexing, the PIO pin ownership transfer, the `is_streaming` flag pattern) have already been found.
- A "cleaner" design that misses one of those pitfalls will cost you weeks of debugging.
- New patterns introduce new pitfalls. The existing ones have known pitfalls — already documented in [`02_Safety_and_Hazards.md`](02_Safety_and_Hazards.md).

After you've got the MSIF working end-to-end *using the existing patterns*, then by all means refactor. The architecture should evolve, just not before you understand it.

A few specific things you might be tempted to "improve" but should leave alone (at first):

- The long `if(strncmp(...))` chain in `app_dispatch`. It's not pretty, but it's debuggable. A function-pointer dispatch table is "cleaner" but harder to trace when a command does the wrong thing.
- The `goto reboot` in `main()`. C's not Java; `goto` for cleanup is fine and idiomatic in embedded code.
- The duplicated coefficient constants in `app_cmd_isp` and `core1_ictl`. Pull them into a `#define` in a header *after* you've confirmed the system works.
- The `dma0_last_written` / `dma1_last_written` globals. They're ugly globals, but they're the single shared word between an ISR and a polling consumer — which is exactly the use case `volatile int` was made for.

The rule of thumb: change *features*, not *architecture*, in your first month. By then you'll have a sense for what's load-bearing and what isn't.

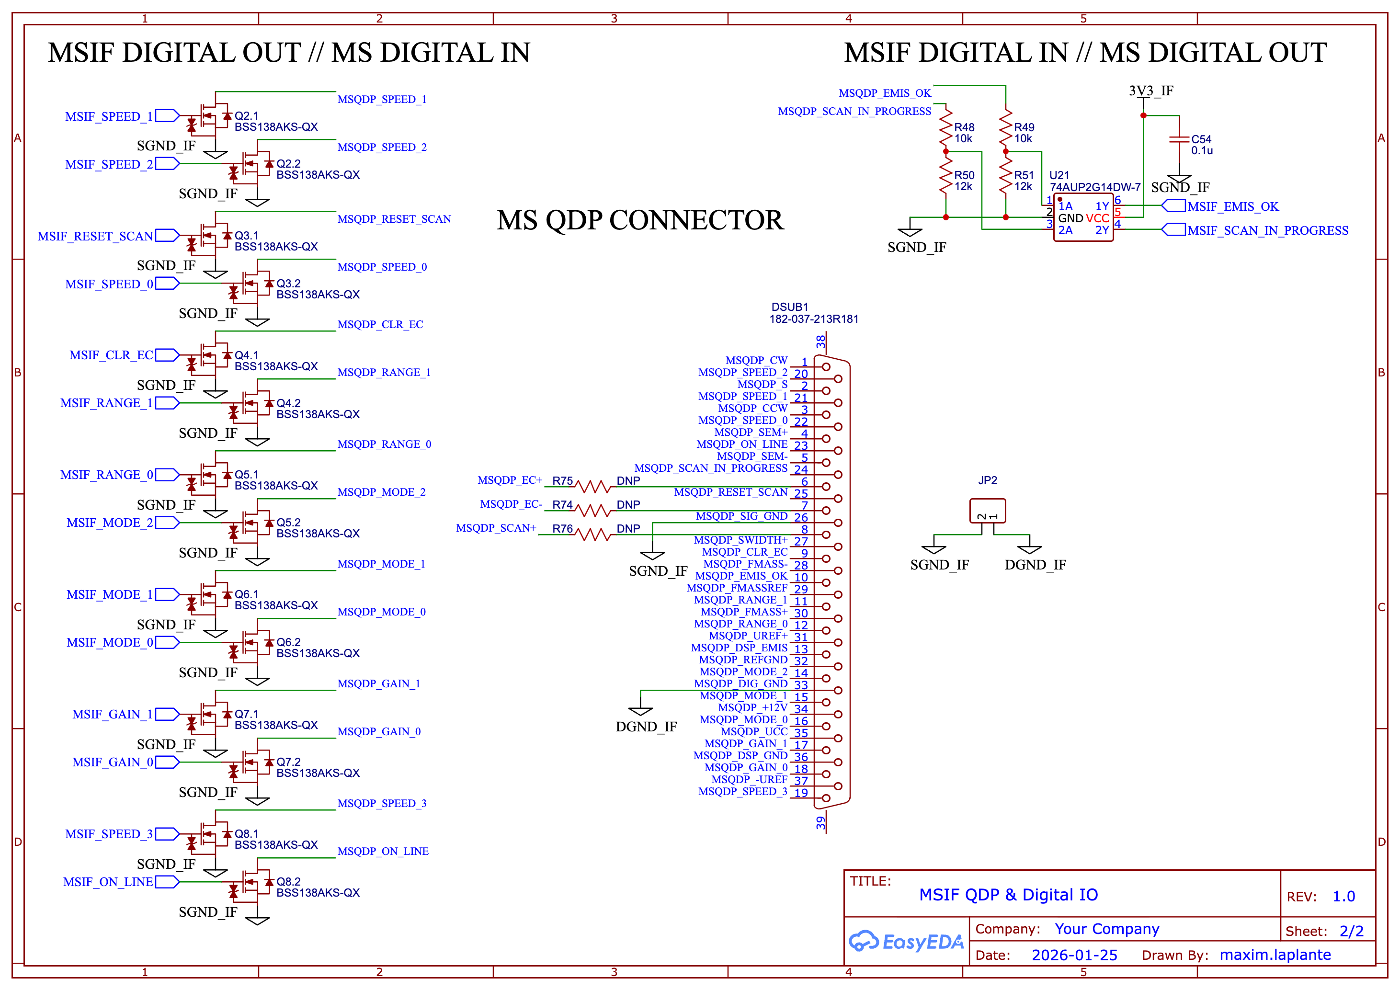
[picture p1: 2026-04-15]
MSIF_dev/MSIF_Docs/MSIF QDP.png

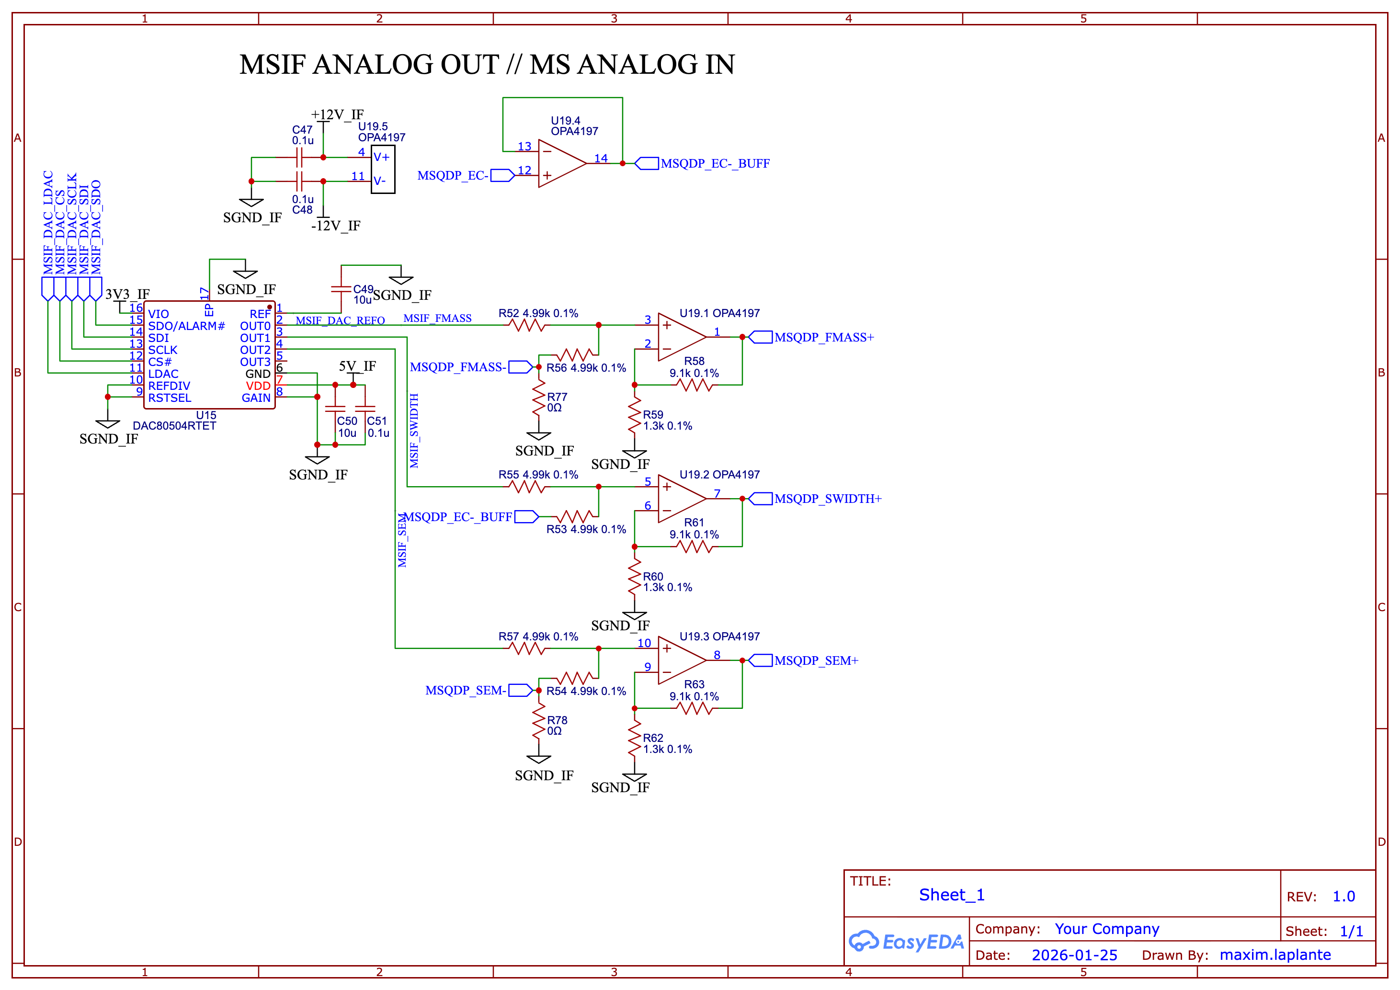
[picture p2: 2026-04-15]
MSIF_dev/MSIF_Docs/MSIF Analog.png

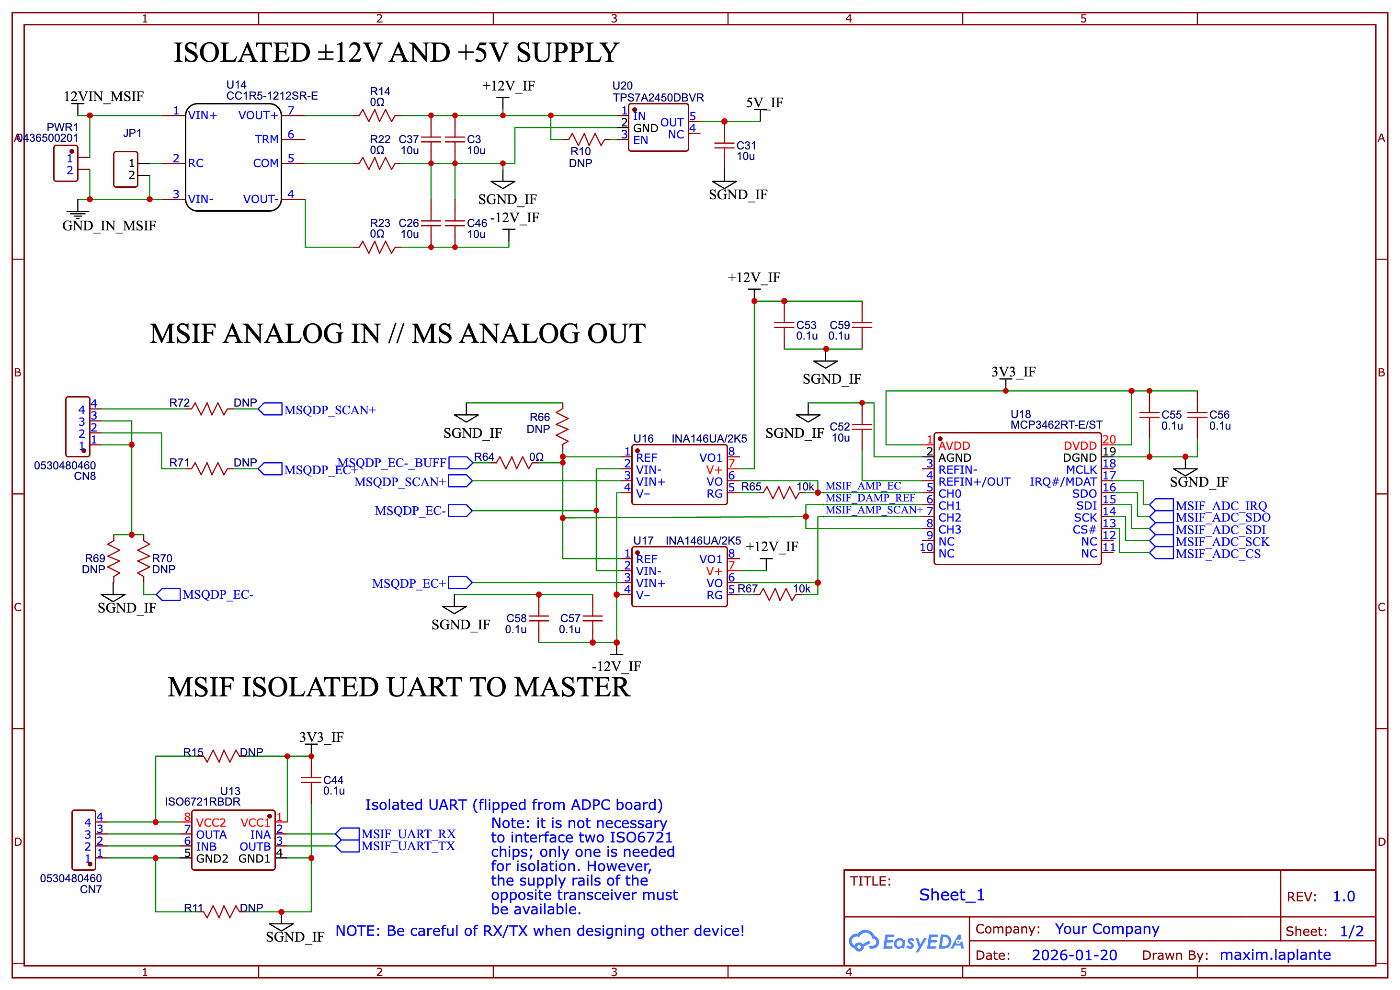
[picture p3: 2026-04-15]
MSIF_dev/MSIF_Docs/MSIF Main.png

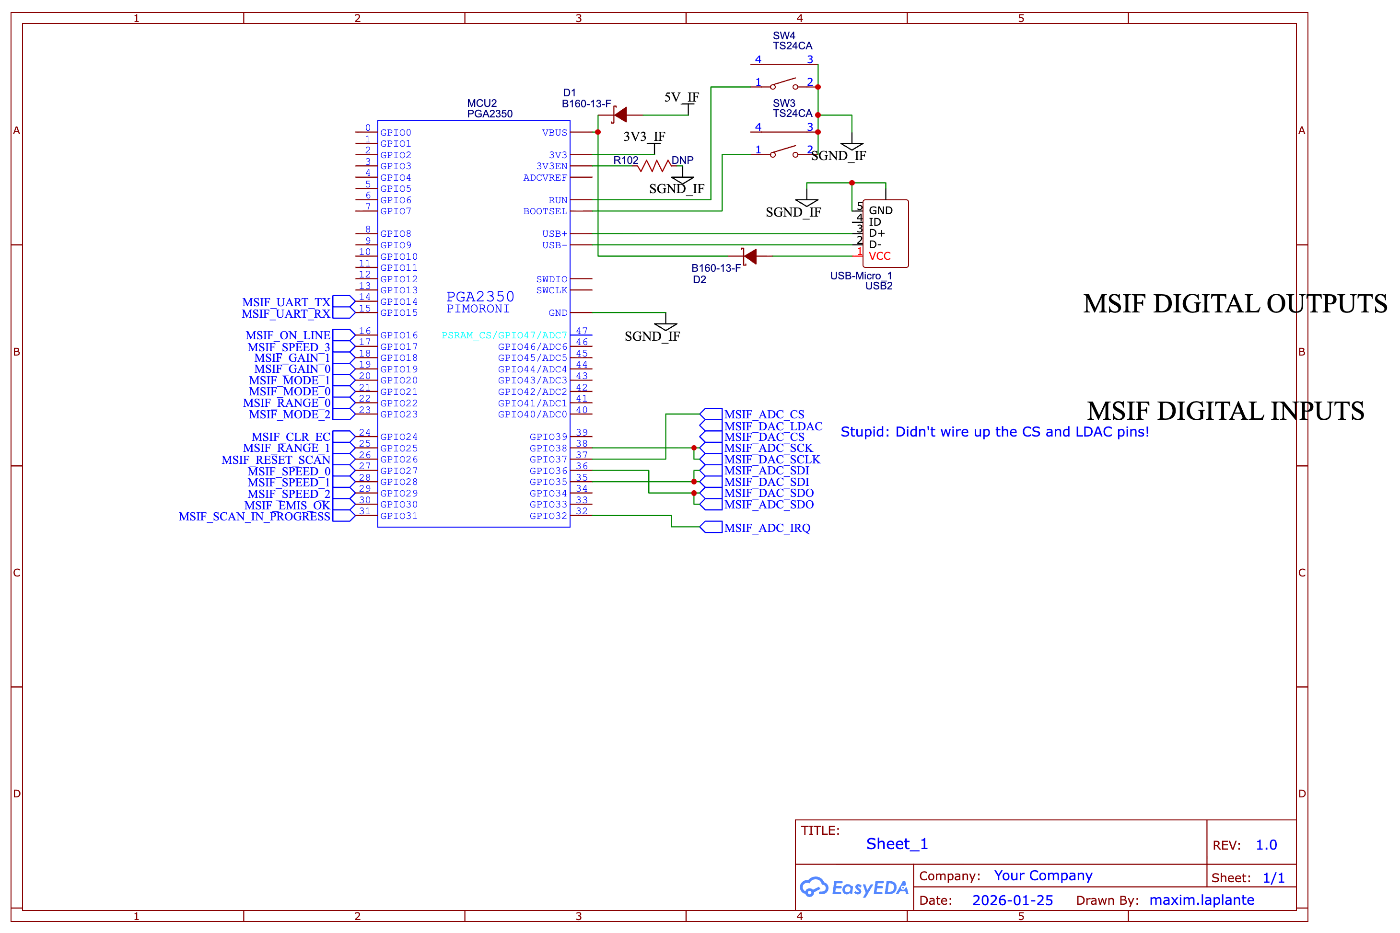
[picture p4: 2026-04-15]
MSIF_dev/MSIF_Docs/MSIF MCU.png

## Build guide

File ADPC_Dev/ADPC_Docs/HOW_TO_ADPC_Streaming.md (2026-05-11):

# ADPC User Guide

## Before You Begin

_AI Generated_

**Startup sequence** — the firmware waits for a single keypress before it begins.
`script.py` handles this automatically. If connecting manually (e.g. with a terminal emulator), send any character to get past the boot prompt.

**`start` must be the first command.** It initializes the ADCs, the PGIA, and the H-bridge outputs. Nothing else will work correctly until this is done.

**The RUN button** on the ADPC hardware can be pressed at any time to force-break a stuck condition (hung stream, blocked loop, etc.) and return to a clean shell prompt.

**`q` reboots the device into USB flash mode** for programming. The firmware is no longer running after this — you must flash new code before the device can be used again.

---

## Serial Shell Reference

Connect via `script.py` (recommended) or any serial terminal at **115200 baud**.

### Initialization

| Command | Description |
|---|---|
| `start` | **Start here.** Initializes ADCs, PGIA, and enables all H-bridge PWM and phase outputs. |
| `init`  | Lower-level initialization only (no PWM/phase enable). Prefer `start`. |

### Output Control

| Command | Description |
|---|---|
| `level <n>` | Set PWM level for all H-bridges. |
| `level` | Print current level. |
| `phen` | Enable phase outputs on all H-bridges. |
| `phd` | Disable phase outputs on all H-bridges. |
| `pwmen` | Enable PWM on all H-bridges. |
| `pwmd` | Set all PWM levels to zero. |
| `sdith <val>` | Set output level using spatial dithering across phases (float, e.g. `sdith 0.15`). |

### Current Control Loop

| Command | Description |
|---|---|
| `isp <amps>` | Set the current setpoint in amps (e.g. `isp 2.5`). Valid range: −10 to 100 A. |
| `ictl` | Toggle the closed-loop current controller on core 1. Run again to stop it. |
| `coeff i <val>` | Set the integrator coefficient (e.g. `coeff i 0.25`). |
| `coeff p <val>` | Set the proportional coefficient (e.g. `coeff p 0.75`). |

### Current Programs

A *current program* is a sequence of current setpoints stepped through at a fixed timestep.

| Command | Description |
|---|---|
| `iprog` | Interactively enter a current program. Prompts for timestep (ms) then setpoints one by one. Type `END` to finish. |
| `irun` | Run the loaded program. Press any key to cancel early. |
| `irun stream`  | Run the loaded program while simultaneously streaming raw ADC data. Stops automatically when the program ends. |

### Data & Diagnostics

| Command | Description |
|---|---|
| `rstream`  | Stream raw ADC data over USB. Send any character to stop. |
| `r0 <n>` | Print the last `n` raw values from ADC channel 0 (DMA buffer). |
| `r1 <n>` | Print the last `n` raw values from ADC channel 1 (DMA buffer). |

### System

| Command | Description |
|---|---|
| `q` | **Reboot to USB flash mode.** New firmware must be flashed before the device can be used again. |

---

## Python Scripts

### `script.py` — Interactive Shell

Provides a transparent passthrough to the firmware shell with added support for streaming data capture and CSV program loading.

**Usage:**
```
python3 script.py [/dev/cu.usbmodem<XXXX>]
```
If only one USB modem device is found, it is selected automatically.

**Additional commands available inside `script.py`:**

| Command | Description |
|---|---|
| `rstream` | Stream ADC data. Press **Enter** to stop. Data is saved automatically to `logs/`. |
| `irun stream` | Run the loaded program with ADC streaming. Stops automatically at program end. Data saved to `logs/`. |
| `iprog <file.csv> [timestep_ms]` | Load a current program from a CSV file instead of typing setpoints manually. See CSV format below. |
| `q` | Send reboot command to firmware and exit the script. |

#### CSV File Format for `iprog`

One setpoint per line, in amps. Example:

```
500
1.0
1.5
2.0
1.5
1.0
0.5
END
```

- The first line is used as the **timestep in milliseconds** if no `timestep_ms` argument is provided on the command line. If `timestep_ms` is given explicitly, the first line is treated as a setpoint.
- `END` is optional — the file ends when no more lines remain.
- Non-numeric lines and blank lines are skipped.
- A maximum of 128 setpoints can be loaded (firmware limit).

**Examples:**
```
# Use first line (500 ms) as timestep:
python3 script.py iprog my_program.csv

# Override timestep to 250 ms:
python3 script.py iprog my_program.csv 250
```

---

### `graphing.py` — Log Viewer

Plots saved ADC log files from the `logs/` directory.

**Usage:**
```
python3 graphing.py
```

On launch it lists all available log files and prompts:

| Input | Behavior |
|---|---|
| *(blank)* | Plot the most recent log file. |
| A number (e.g. `3`) | Plot the 3 most recent log files. |
| A filename | Plot that specific file. |

Each ADC channel is plotted as a separate subplot with a shared time axis. Time is interpolated linearly between the recorded start and stop timestamps.

---

## Log File Format

Log files are saved to `logs/` by `script.py` and are plain text CSV files readable in any spreadsheet application.

**Filename:** `log [YYYY-MM-DD HH-MM-SS].txt`

**Structure:**
```
# time_start: 2025-01-15 14:32:01
# time_stop:  2025-01-15 14:32:45
CH 0, CH 1, CH 2
-1042, 832, 1205
-1038, 829, 1201
...
```

- Lines 1–2: start and stop timestamps (used by `graphing.py` to reconstruct the time axis).
- Line 3: channel header. Channel IDs correspond to MCP ADC channel numbers.
- Remaining lines: one sample per row, comma-separated. Channels with missing samples for a given row are left blank.

Values are signed 24-bit integers decoded from the raw ADC words.

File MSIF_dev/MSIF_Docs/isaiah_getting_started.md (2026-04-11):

## MSIF Development Getting Started

Now that we've got the pico software development kit (SDK) up and running, let'stake a look at the overall structure of the project and where things can get started.

From the top-level down:

1. Provide a clean interface by which a controller can communicate mass spec configuration, "programs", and data streaming configurations/requests.

2. Communicate with another controller (ADPC) over UART

3. Translate abstract requests (e.g. "set mass target to x" or "scan from a to b") into QMS-112 remote control actions (e.g. set FMASS+ analog to 3.2V)

4. Time and organize these actions 

5. Interface with MSIF hardware to perform these actions

Let's talk a bit about the hardware tasks because those should probably be the starting point. There are essentially four things between the MSIF RP2350 and the QMS remote control QDP connector.

1. MSIF Digital Inputs: read outputs from the QMS to RP2350 GPIO inputs

2. MSIF Digital Outputs: convert RP2350 3.3V GPIO outputs to QMS-accepted digital inputs

3. MSIF Analog Inputs: convert analog readings to numeric representations that the RP2350 can request from the ADC chips.

4. MSIF Analog Outputs: provide analog signals to the QMS using a digital-to-analog converter (DAC) according to numeric outputs from the RP2350.

## Coding

### Getting the code and prepping the space.

You can get the code I've started by doing:

`git clone https://github.com/TarbFela/Capstone.git`

You'll want to do this into a directory that is convenient for you. This will create a folder called `Capstone` within that directory. This contains `MSIF_dev/`, which is where you should develop your code. Please put any documentation in the relevant directory.

To get started with this, get into that directory:

`cd Capstone/MSIF_dev`

Then set up the build directory:

`mkdir build`

Go to that directory:

`cd build`

And run CMake so that you can compile the code:

`cmake -DPICO_BOARD=pico2 ..`

_You may need to set your PICO_SDK_PATH; find where `pico-sdk/` lives on your computer, copy that path, and paste it into_:

`export PICO_SDK_PATH=______`

Once this is done you should be all set to compile the project (from the `build/` directory):

`make`

Or remove all compiled files:

`make clean`

### Git

When you make changes, do:

`git commit <files> -m "<some comment>"`

When uou make new files, you'll have to precede that with:

`git add <files>`

This makes it easy to undo changes or mix-and-match. Once you're set up with a Github account, you'll be able to:

`git push origin main`

Which saves those changes to the Github servers and allows me to retrieve them. **Also, regularly run**:

`git pull`

This pulls any changes I've pushed. If you don't do this you'll have to mess around with git's "merging" tool which can be a bit of a pain.

### Digital Inputs: A starting point

The easiest place to start is the digital inputs. Once you have serial debugging (`printf()`) working, it's easy enough to start reading inputs. Right now, the code I've provided looks for inputs over USB; if the input is a "q" then it goes into USB flash mode so that new programs can be loaded; otherwise it just tells you that it received your input.

```
    while(1) {
        int uii = stdio_getchar_timeout_us(100);
        if(uii != PICO_ERROR_TIMEOUT) {
            char ui = (char)uii;
            // QUIT
            if (ui == 'q') break;
            else printf("Input recieved! [press q for BOOTSEL mode]\n");
        }
    }
```

The next step is to get the SDK's `gpio` functions working. A good resource for all of the relevant function is the SDK itself. It should exist somewhere locally on your machine, but it also exists on Github where you can easily reference it:

https://github.com/raspberrypi/pico-sdk/tree/master/src/rp2_common

From here you can navigate to `hardware_gpio/include/hardware/gpio.h`. This same patterns extends for all of the tools you'll be using, including `uart.h` and `spi.h`. 

You'll need to put `#include "gpio.h"` in your main.c file. You'll also need to put `hardware_gpio` in the `CMakeLists.txt` file under `target_link_libraries`. You may have to run the `cmake` command again (see above). Also refer to the gpio examples from Raspberry Pi  (also on Github). GPIOs need to be configured, then you can read them as you wish, assign the results to variables, and print them out with `printf("You variable is %d \n", x);` or similar. You can trigger these prints by putting them in `if() {}` statements similar to the one for "q" in the template. 

Now comes the MSIF-specific stuff!

### MSIF Digital Inputs

You'll want to refer to the schematics and define macros for the pins according to their purposes/names. Find the PGA2350 symbol and look at the digital io page of the schematic. Use something like `#define MSIF_EMIS_OK_IN_PIN 30` for all the pin defs (for the digital outputs as well). Then write code to configure the inputs as inputs, the outputs as outputs, and write functions to read/set these. You can write the functions in `main.c` for now; we'll move them to separate source/header files later.

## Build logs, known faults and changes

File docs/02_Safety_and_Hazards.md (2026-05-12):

# Safety & Hazards

This system drives large currents through real heaters. There are also a number of software footguns that have bitten developers (including the original author) and will bite you. Read this section before you start changing the firmware.

The hazards are ordered roughly by potential consequence — hardware issues first, software second.

---

## ⚡ Hardware hazards

### 1. Always disable `PH_EN` before reconfiguring PWM

The `PH_EN` ("phase enable") pin on each MPHB-002 channel is a **gate** that disconnects the power stage without interrupting the PWM clock. The intended sequence for changing PWM safely is:

1. Set `PH_EN` low (`mphb_set_ph_en(HBxX, false)` or `mphb_set_ph_en_all(false)`).
2. Reconfigure PWM levels, change the differential level, switch dithering on/off, etc.
3. Re-enable `PH_EN`.

If you change the PWM levels *while `PH_EN` is high*, the power stage will instantaneously follow — which is fine if the new level is close to the old one, but very much not fine if you're going from a tiny duty cycle to a large one. Always cycle `PH_EN` for any big change.

### 2. The "level" is differential about a common-mode duty cycle

`mphb_set_dlevel_all(level)` does **not** set the duty cycle directly. It sets a *differential* level about `mphb_pwm_cm_level` (default: `MPHB_PWM_WRAP / 2 = 500`, i.e. 50% duty). Concretely:

```c
// Inside mphb_set_dlevel():
mphb_set_levels(i,
    mphb_pwm_cm_level + (dlevel + 1)/2,    // A side
    mphb_pwm_cm_level - (dlevel / 2));     // C side
```

So `dlevel = 0` produces matched 50%/50% PWM on the two halves and **zero net voltage across the load**. Positive `dlevel` drives one way, negative the other. The maximum useful range is roughly `±500` (full positive or full negative drive), but the firmware clamps the *closed-loop* controller to `±0.3` of full scale (i.e. ±150 PWM counts) — see `core1_ictl()`. There is no equivalent clamp on the *open-loop* `level <n>` command. Be careful when testing manually.

### 3. The current setpoint scaling is hand-calibrated

In `app_cmd_isp()`:
```c
int32_t sp_scaled = sp * 162.4203245 - -25.41180842;
```
These coefficients are calibration values for a *specific physical setup* (a specific shunt resistor, a specific PGIA gain, a specific common-mode). **If you change any of those, the scaling is wrong and the controller will drive the wrong current.** Re-derive them by running `rstream` at known currents, fitting a line through the data, and updating `app_cmd_isp()` and the matching line in `core1_ictl()` (yes, the constants are duplicated — there's a TODO to fix this).

### 4. There is no over-current shutdown in firmware

If the controller becomes unstable (e.g. because someone set bad PI coefficients with `coeff i` / `coeff p`), nothing in firmware will save the hardware. 

Practical mitigation: **start with `phen` off, then enable** after you've verified the level is sensible:
```
>> start
>> level 0
>> phen           ← only after confirming
```

### 5. The RUN button is a hard reset

Useful when the firmware is stuck (hung in a busy-wait, etc.) without wanting to reflash. It does not save state — DMAs are aborted mid-transfer, the USB session drops, etc. Generally safe to use because the MPHB-002 hardware should bring outputs to zero when PWM stops, but verify on your specific setup.

### 7. The ADC nIRQ pin needs an *external* pull-up

This is a documented quirk of the MCP3x6xR family: without an external pull-up on the nIRQ line, **the ADC will not perform conversions**. The ADPC board has these pull-ups installed. If you breadboard one of these ADCs onto a new board for development, you must add the resistor.

---

## 💾 Software hazards

### 1. Shared state between cores is `volatile` but not atomic

`ui_state` lives in shared RAM and is touched by both cores. It's declared `volatile`, which prevents the compiler from caching its value in a register, but it does **not** make multi-byte writes atomic. If core 0 is updating `ui_state.level` (a float, 4 bytes) at the moment core 1 reads it, core 1 can in principle observe a half-written value.

In practice the writes are infrequent enough and the consequences of one bad value are mild enough (the next loop iteration corrects it) that this hasn't been observed to cause problems. But if you add a multi-word shared state — say, a struct of calibration coefficients written from core 0 and read from core 1 — wrap the updates in `multicore_lockout` or use the FIFO to message them.

### 2. The DMA-tracking globals are also volatile-but-not-atomic

`dma0_last_written` and `dma1_last_written` are written from inside ISRs and read from both cores' main loops. Each is a single `int`, so the read/write is atomic on the RP2350 (single 32-bit memory access). You can rely on observing 0, 1, or 2 — never a torn value.

**However:** there is a subtle window where the ISR has updated `dma_last_written` but the DMA `transfer_count` register hasn't yet been re-initialized for the next half. Code that mixes `dma_last_written` and `dma_channel_hw_addr(...)->transfer_count` (as `core1_ictl()` does) must guard against this — the existing code uses a `goto start` to retry whenever it detects an inconsistency. If you write new code that consumes these globals, follow the same pattern.

### 3. DMA buffer indexing is a little confusing

The buffers are arranged as one contiguous block of `2 × DMA_BUFF_SIZE` samples, with buffer A in the lower half and buffer B in the upper half. To compute the current write position you have to flip the meaning of `lw_current`:

```c
// if dma0_last_written == 1, then DMA A just finished;
// DMA B is now writing, into the upper half (base = DMA_BUFF_SIZE).
// if dma0_last_written == 2, then DMA B just finished;
// DMA A is now writing, into the lower half (base = 0).

int current_base = (2 - lw_current) * DMA_BUFF_SIZE;
```

The previous author originally wrote `((2 - lw_current) * DMA_BUFF_SIZE + DMA_BUFF_SIZE + ...) & mask`, which silently reads from the wrong buffer — this was a real bug, found by hand, and the fix went into `core1_ictl()`. If you copy this pattern elsewhere, double-check by walking through both cases.

### 5. `printf()` from inside the streaming loop will corrupt the data

When `rstream` is active, stdio over USB is muted (`stdio_set_driver_enabled(&stdio_usb, false)`) so that `printf` calls produce no output. **But** the USB CDC is still being written to directly with raw DMA bytes. If you add a `printf` inside the streaming path — or, more sneakily, if a function deep inside one of your handlers has a debug `printf` — the bytes will interleave with the binary stream and the host-side parser will choke.

The convention in this codebase is: wrap any potentially-streaming debug print in `if(!s->is_streaming) printf(...)`. Several existing functions already do this. Follow the pattern.

### 6. `is_streaming` must be cleared on every exit path

`app_cmd_rstream` and `app_cmd_irun_streaming` both set `s->is_streaming = true` at entry. They must clear it on **every** exit path or `app_shell_task` will think the device is still streaming and behave strangely (no prompt, no echo, etc.). The current code clears it in the normal path; double-check this if you add new exit conditions.

### 7. The MCP PIO driver can only be initialized twice

In `mcp_pio_init()`:
```c
static int call_count = 0;
if(call_count == 0) { pio = pio0; ... }
else if (call_count == 1) { pio = pio1; ... }
else { panic("\n\tPANIC!! PIO INIT MAY ONLY BE CALLED TWICE.\n"); }
```
There are only two PIO blocks on an RP2350, and each MCP ADC consumes one. If you initialize a third instance, the firmware will panic at boot. If you need PIO for something else (a custom UART, a fancy SPI, etc.), you must either combine state machines on a shared PIO block or rewrite the driver to claim an unused PIO+SM pair properly.

### 8. The DMA IRQ handler does work that should arguably be elsewhere

The DMA IRQ handlers in `adpc_app_funcs.c` are short, but at one point there was a `>>16` shift loop running inside `dma_irq_handler_0` (now commented out). **Don't do this.** Interrupt handlers should clear the IRQ flag, update one or two volatile flags, and return. Long work inside an ISR will:

- Block other interrupts (USB, the other DMA, the PWM wrap, etc.).
- Get re-entered by the same DMA finishing the next half before you've finished the previous one.
- Make the system's worst-case latency unpredictable.

If you need to post-process samples (sign extension, scaling, decimation), do it on core 1, not in the ISR.

### 10. The `src2/` and `*_Dev/` directories contain stale code

There's a strong urge to copy something from `src2/main.c` or one of the standalone test projects when you need a quick example. Those files **predate the current architecture** and have known bugs and deprecated patterns. Refer to them for inspiration only; do not copy code from them into `ADPC_Data_Streaming/`.

---

## Quick checklist before you flash new firmware

- [ ] All outputs in your test setup can tolerate full-scale PWM if the firmware misbehaves
- [ ] `PH_EN` defaults to off at boot (it does, but verify nothing you added enables it early)
- [ ] No `printf` calls were added to streaming paths without an `is_streaming` guard
- [ ] DMA IRQ handlers are still short (≤ ~5 lines of real work)
- [ ] Any new shared state between cores is either `volatile` *and* single-word, or protected
- [ ] You haven't added a third `mcp_pio_init` call
- [ ] If you changed shunt resistors, PGIA gain, or common-mode, you re-derived the `app_cmd_isp` scaling

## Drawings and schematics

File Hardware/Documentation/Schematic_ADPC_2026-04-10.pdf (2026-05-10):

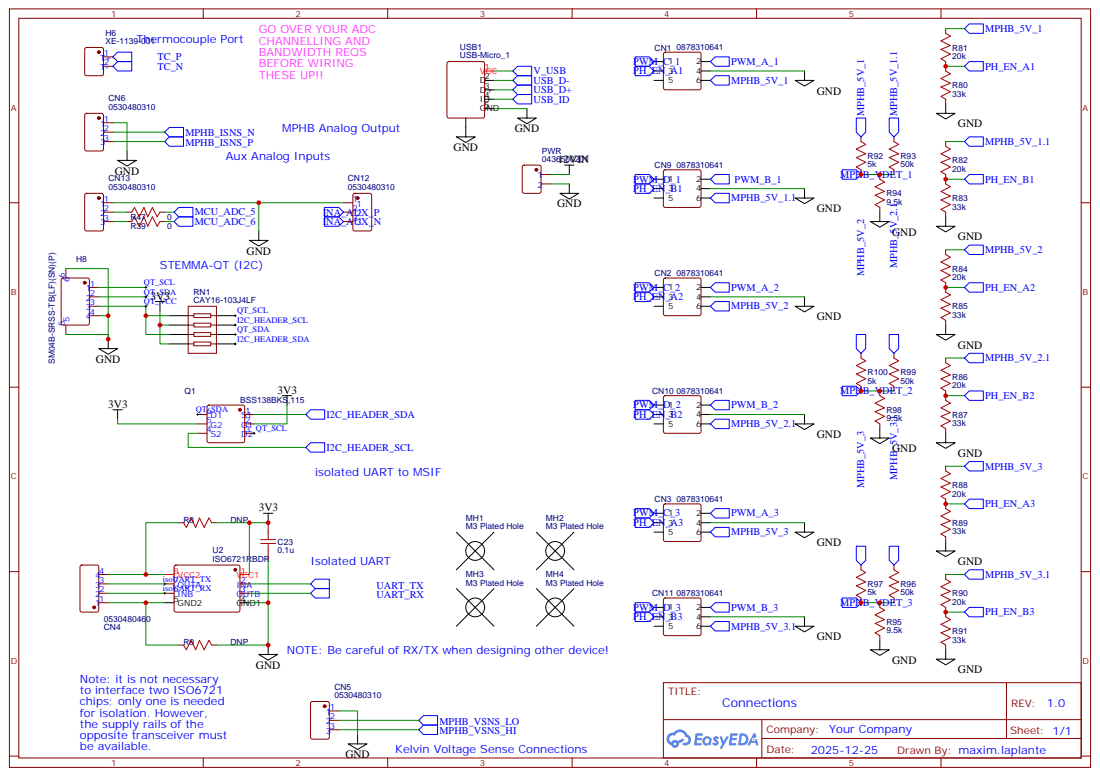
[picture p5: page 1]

GO OVER YOUR ADC
CHANNELLING AND
BANDWIDTH REQS
BEFORE WIRING
THESE UP!!

SM04B-SRSS-TB(LF)(SN)(P)

I2C_HEADER_SCL
isolated UART to MSIF

NOTE: Be careful of RX/TX when designing other device!
GND

Note: it is not necessary
to interface two ISO6721
chips; only one is needed
for isolation. However,
the supply rails of the
opposite transceiver must
be available.

Kelvin Voltage Sense Connections

Drawn By: maxim.laplante

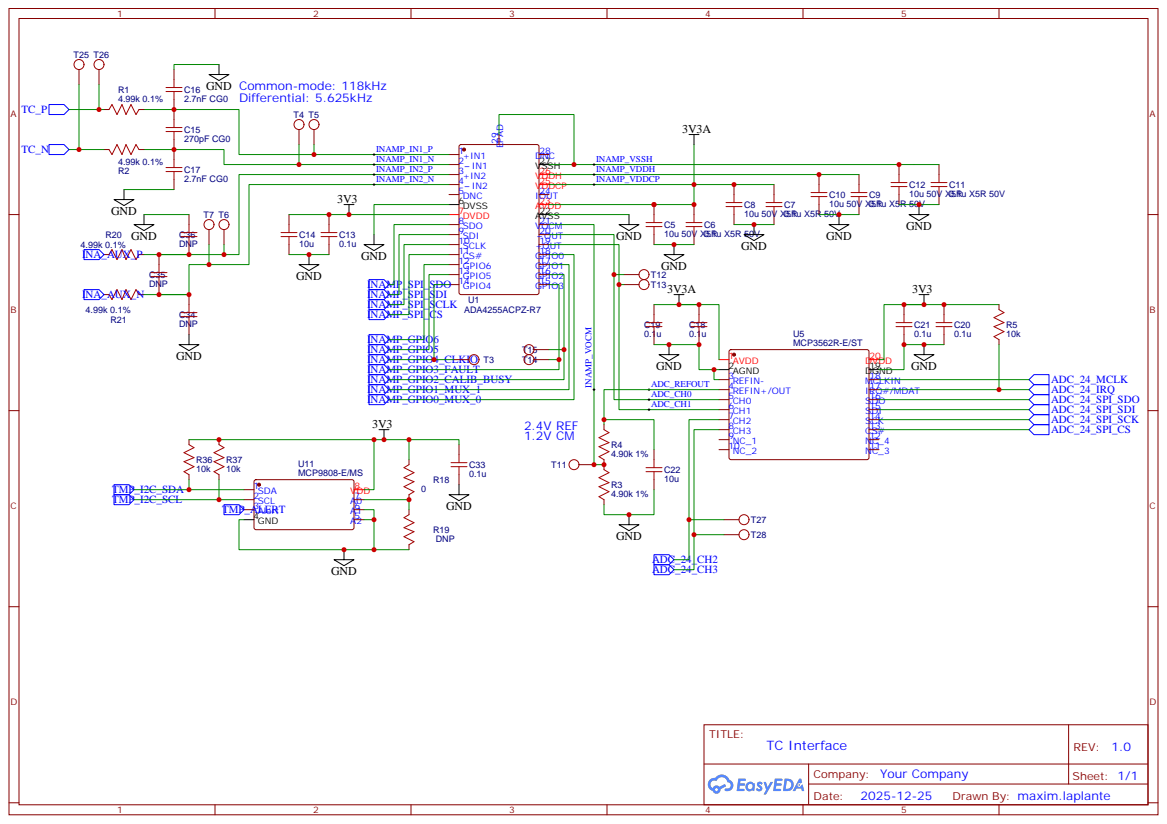
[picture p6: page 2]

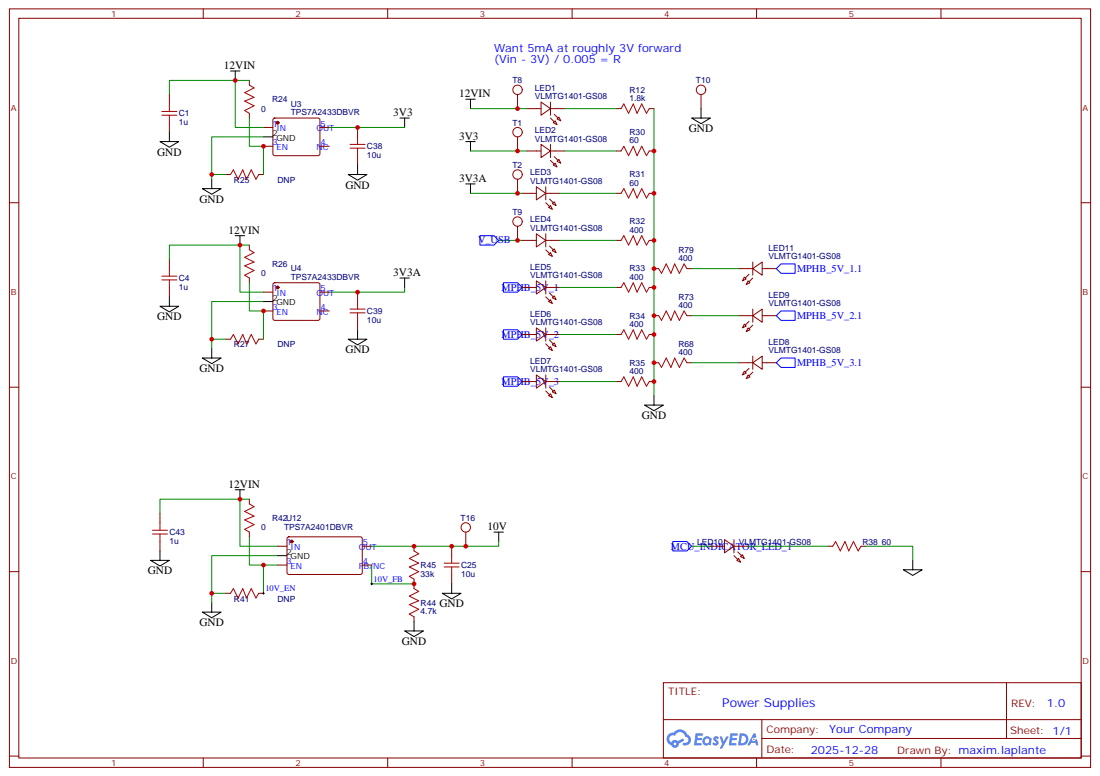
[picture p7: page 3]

Want 5mA at roughly 3V forward
(Vin - 3V) / 0.005 = R

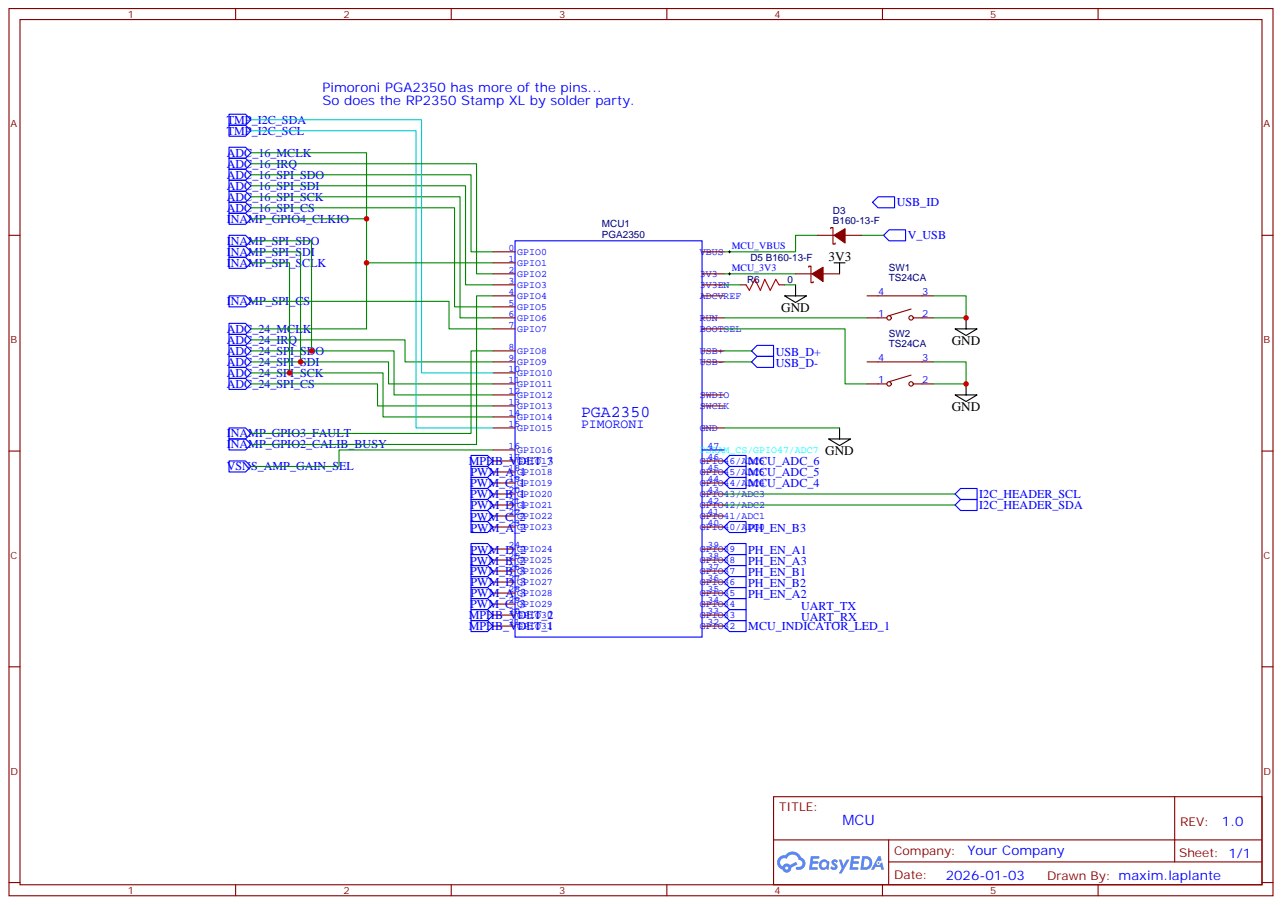
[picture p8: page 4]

Pimoroni PGA2350 has more of the pins...
So does the RP2350 Stamp XL by solder party.

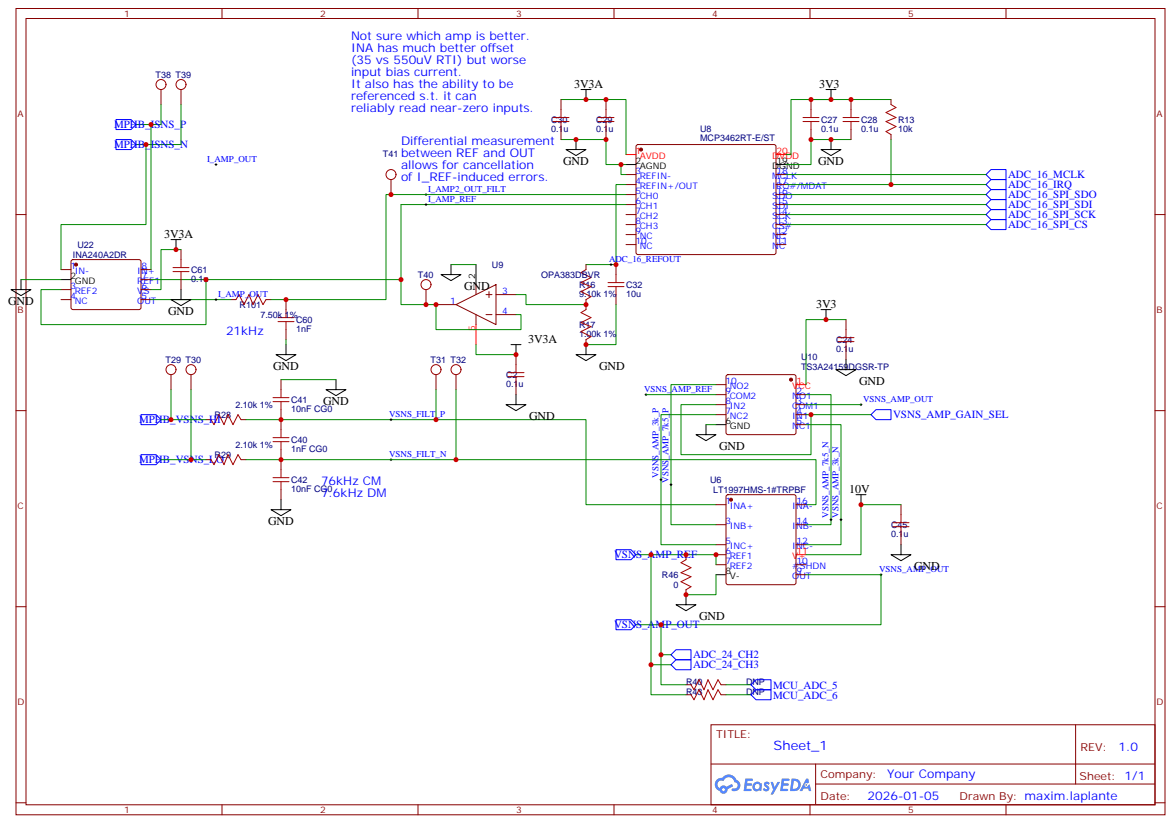
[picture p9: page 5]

Not sure which amp is better.
INA has much better offset
(35 vs 550uV RTI) but worse
input bias current.
It also has the ability to be
referenced s.t. it can
reliably read near-zero inputs.

# ISOLATED 12V AND +5V SUPPLY

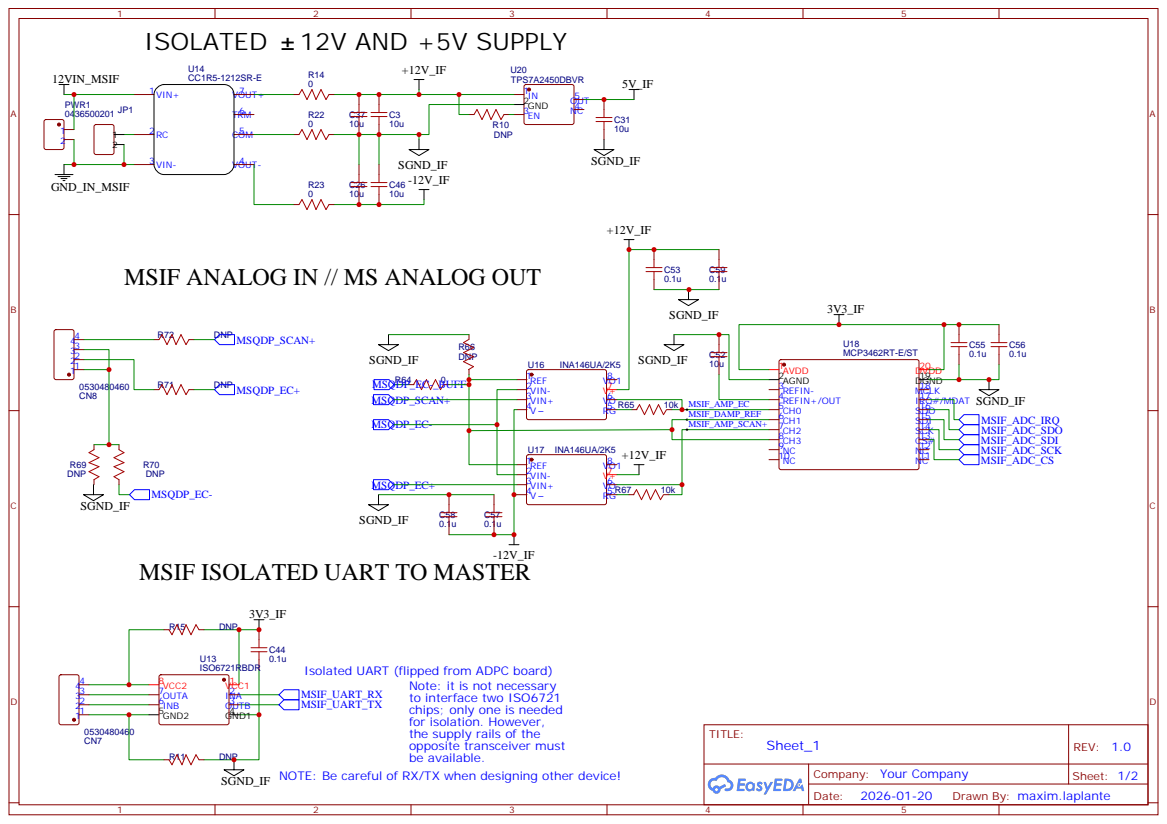
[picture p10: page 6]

MSIF ANALOG IN // MS ANALOG OUT

MSIF ISOLATED UART TO MASTER

Isolated UART (flipped from ADPC board)

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

NOTE: Be careful of RX/TX when designing other device!

MSIF DIGITAL OUT // MS DIGITAL IN | MSIF DIGITAL IN // MS DIGITAL OUT

# MS QDP CONNECTOR

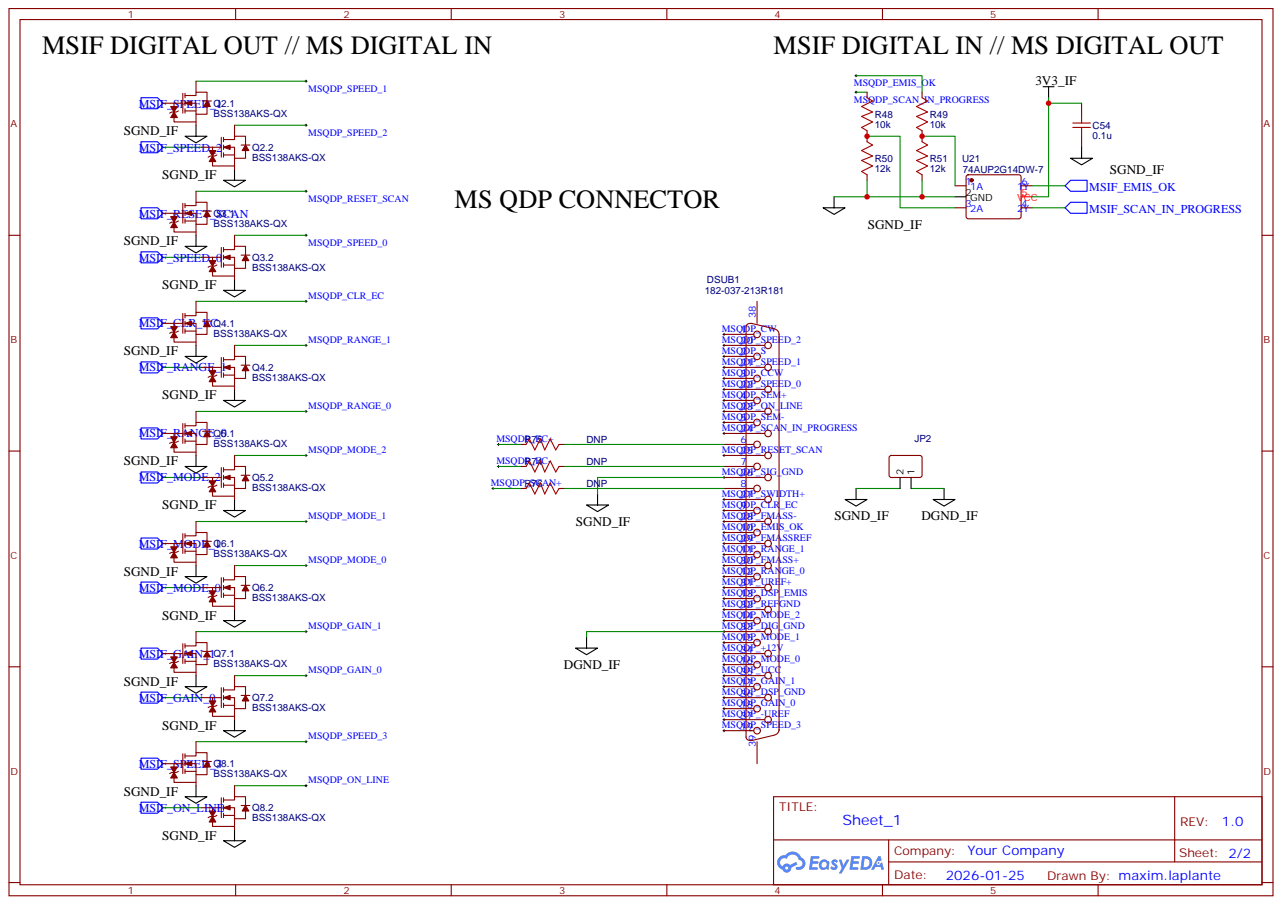
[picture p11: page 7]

# MSIF ANALOG OUT // MS ANALOG IN

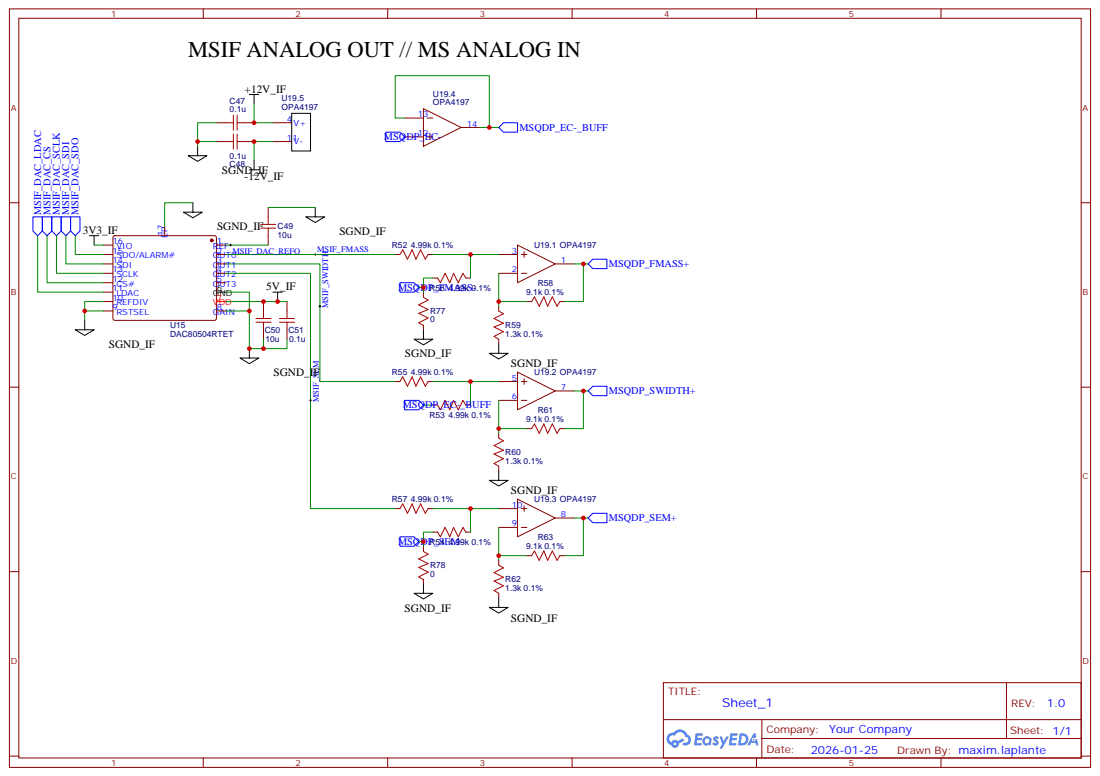
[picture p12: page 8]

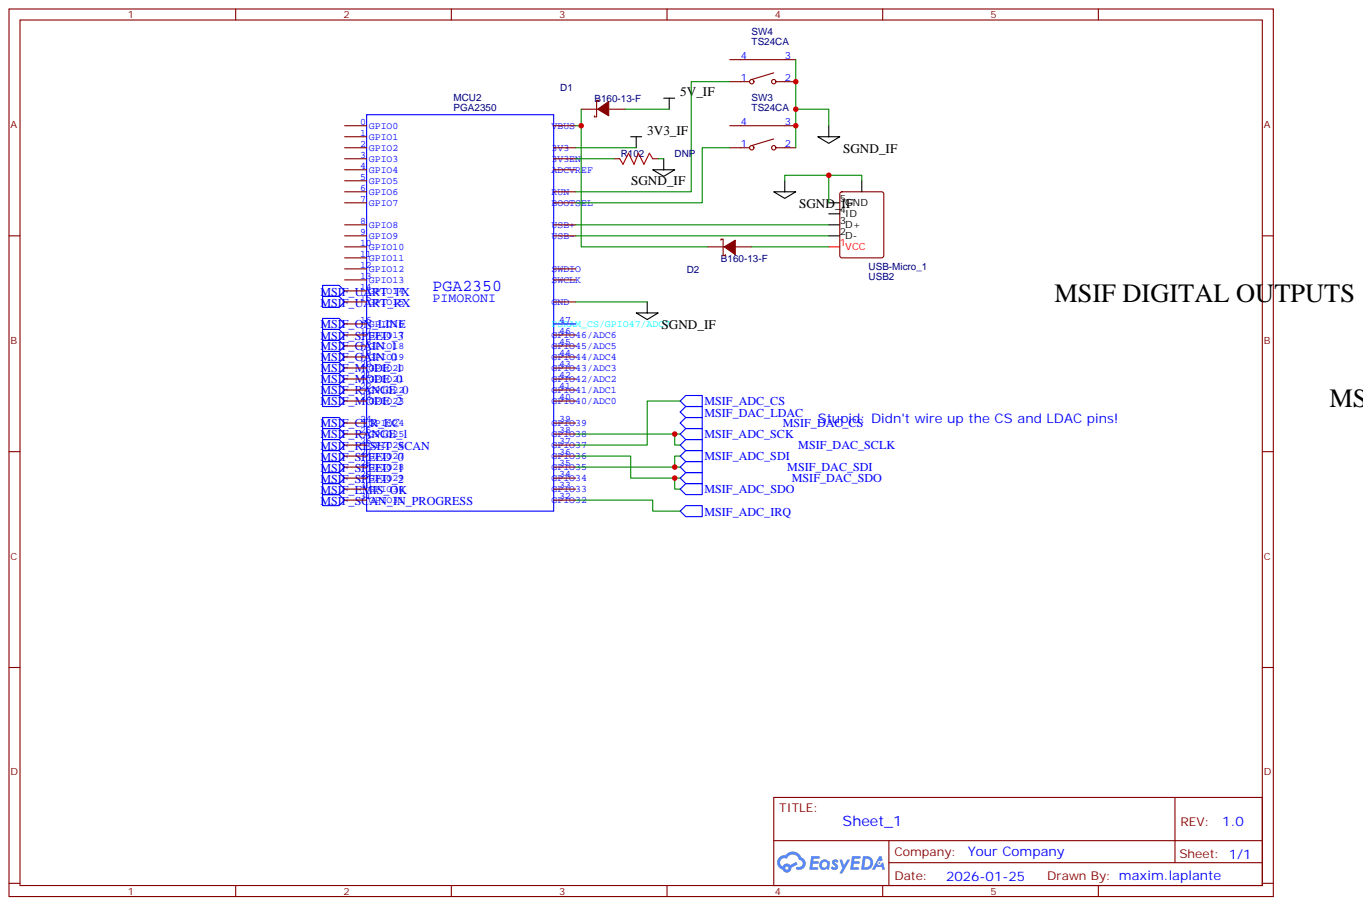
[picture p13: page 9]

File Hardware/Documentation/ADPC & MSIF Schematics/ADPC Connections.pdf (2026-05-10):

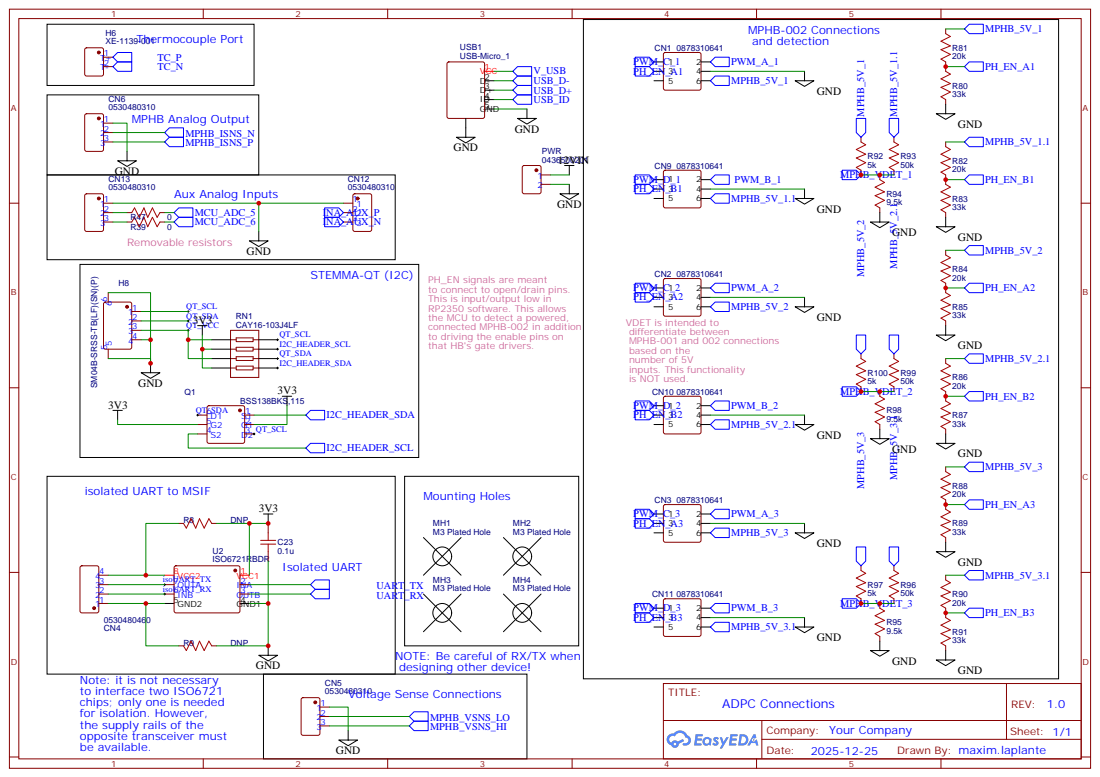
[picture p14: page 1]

PH_EN signals are meant
to connect to open/drain pins.
This is input/output low in
RP2350 software. This allows
the MCU to detect a powered,
connected MPHB-002 in addition
to driving the enable pins on
that HB's gate drivers.

SM04B-SRSS-TB(LF)(SN)(P)

VDET is intended to
differentiate between
MPHB-001 and 002 connections
based on the
number of 5V
inputs. This functionality
is NOT used.
PWM_D_2

isolated UART to MSIF

NOTE: Be careful of RX/TX when
designing other device!

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

Drawn By: maxim.laplante

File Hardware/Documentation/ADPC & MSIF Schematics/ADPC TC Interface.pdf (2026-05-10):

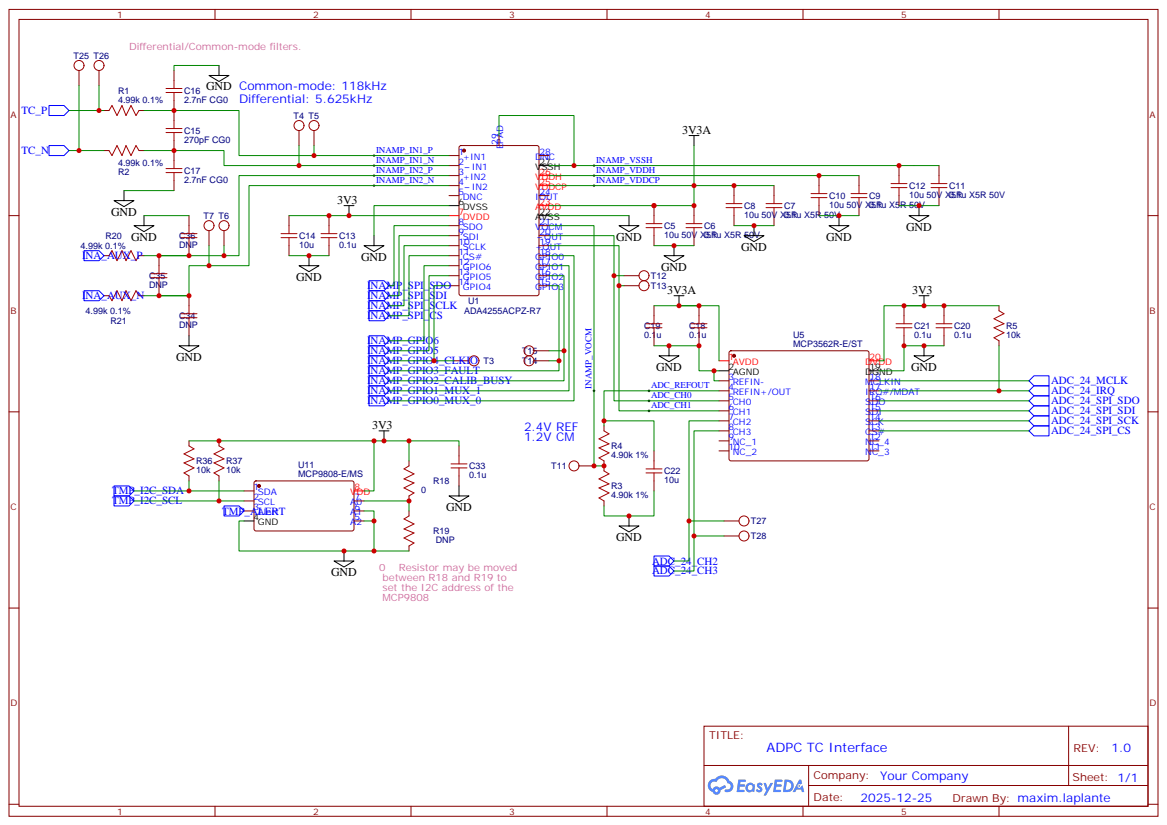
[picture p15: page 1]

Differential/Common-mode filters.

0 Resistor may be moved
between R18 and R19 to
set the I2C address of the
MCP9808

Drawn By: maxim.laplante

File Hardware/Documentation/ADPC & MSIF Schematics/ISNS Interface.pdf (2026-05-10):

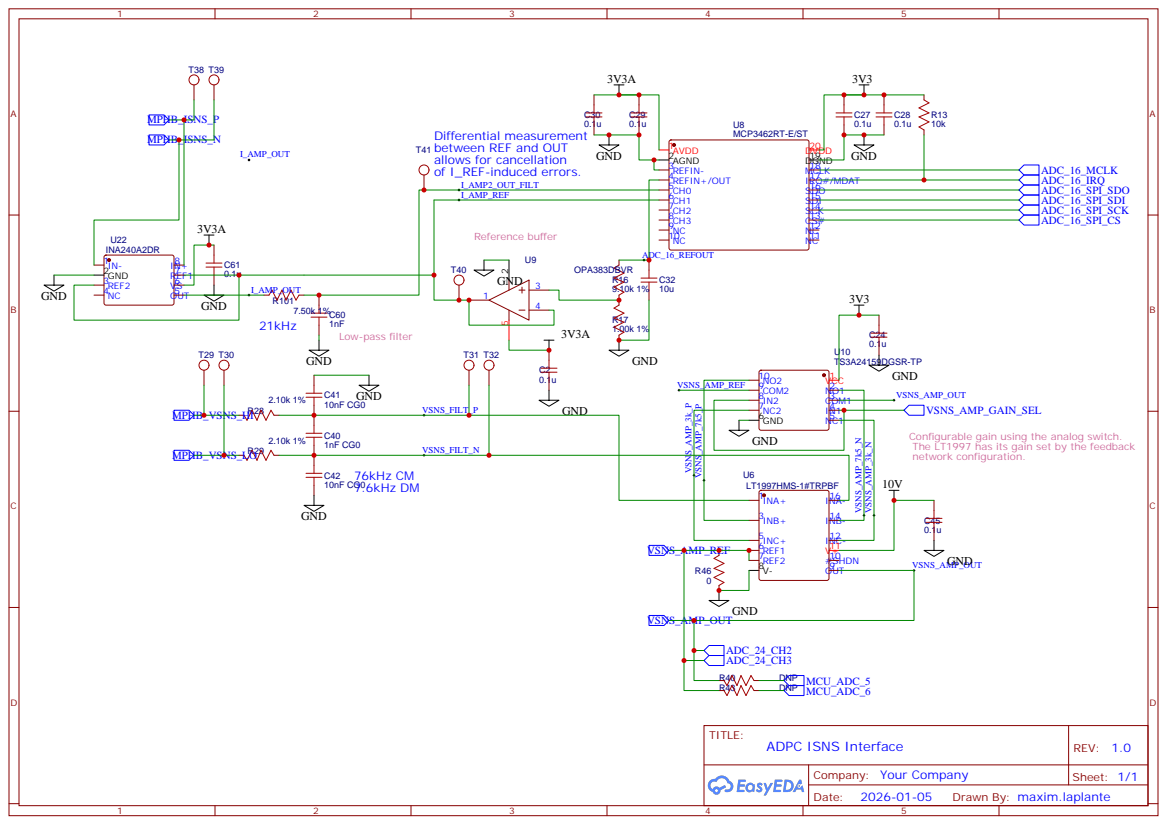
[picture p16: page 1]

Configurable gain using the analog switch.
The LT1997 has its gain set by the feedback
network configuration.

Drawn By: maxim.laplante




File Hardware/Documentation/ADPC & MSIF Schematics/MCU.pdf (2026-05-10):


Drawn By: maxim.laplante

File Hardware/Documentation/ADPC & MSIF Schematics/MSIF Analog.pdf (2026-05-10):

# MSIF ANALOG OUT // MS ANALOG IN


Drawn By: maxim.laplante

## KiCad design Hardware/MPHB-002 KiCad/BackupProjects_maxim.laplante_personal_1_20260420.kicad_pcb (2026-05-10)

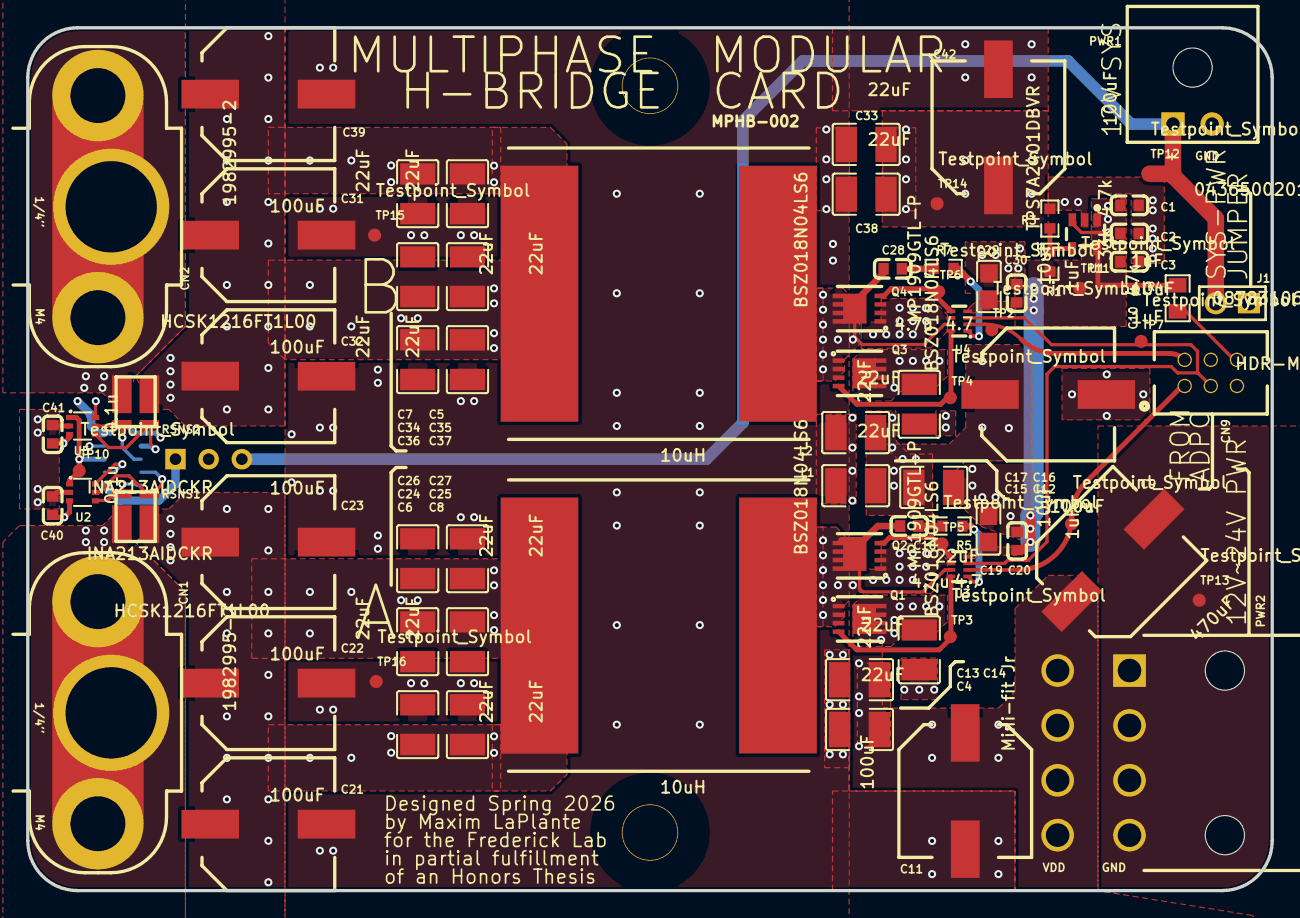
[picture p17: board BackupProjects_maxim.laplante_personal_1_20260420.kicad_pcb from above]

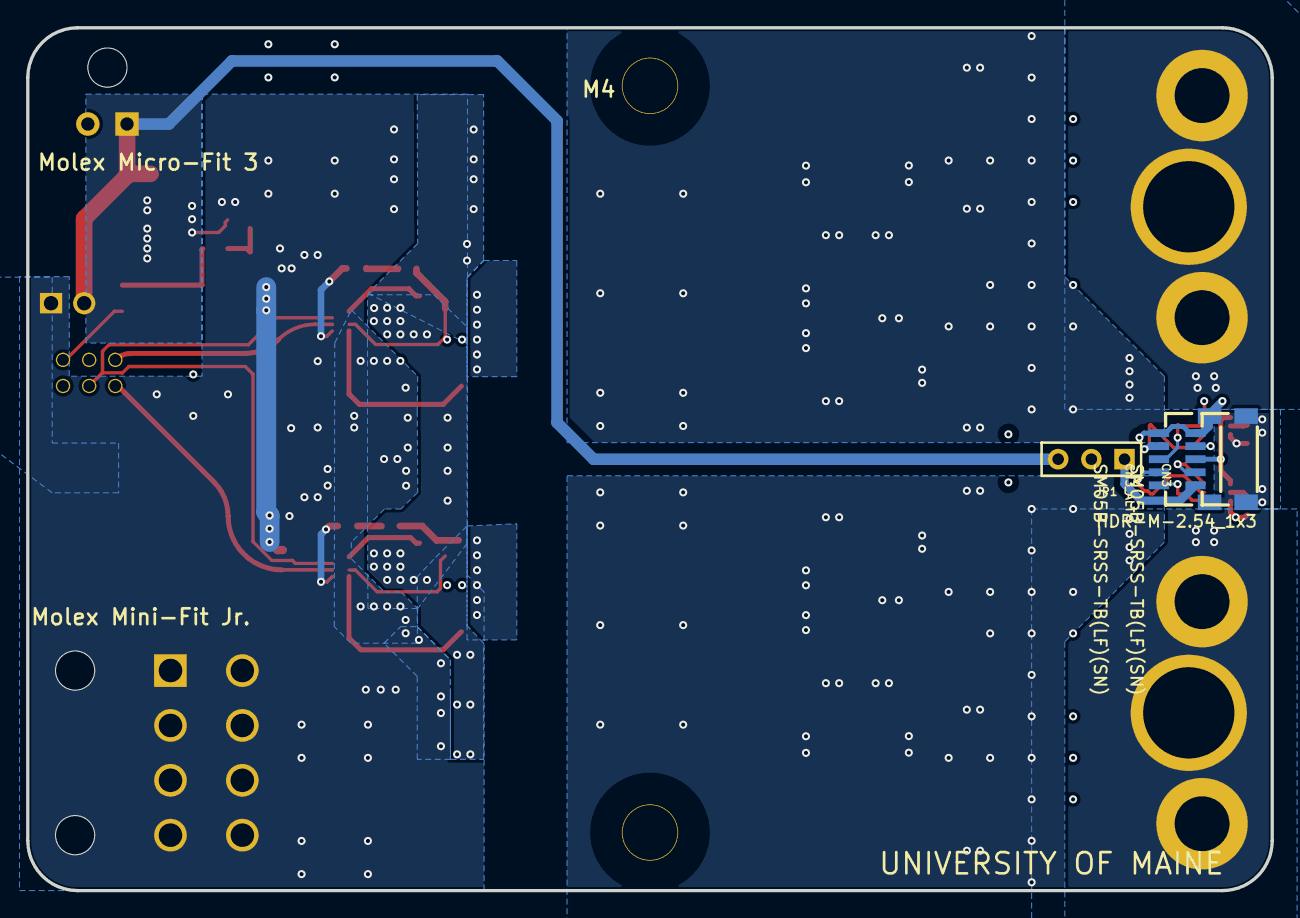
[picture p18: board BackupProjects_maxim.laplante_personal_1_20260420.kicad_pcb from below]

Board: 4 copper layers, 95.2 x 66.0 mm, 87 parts (3 on the bottom side), 32 nets.

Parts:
C1, C3, C20, C30: 1uF; C0603
C2: 10uF; C0603
C4, C5, C6, C7, C8, C12, C13, C14, C15, C16, C17, C24, C25, C26, C27, C33, C34, C35, C36, C37, C38: 22uF; C1210
C9: 470uF; APD_CAP_1012
C10, C11, C21, C22, C23, C31, C32, C39, C42: 100uF; APD_CAP_1012
C18, C28: 4.7u; C0603
C19, C29: 10uF; C0805
C40, C41: 0.1u; C0603
CN1, CN2: 1982995-2
CN3, CN3_ALT: SM05B-SRSS-TB(LF)(SN); CONN-SMD_SM05B-SRSS-TB
CN9: 0878310641
J1: HDR-M-2.54_1x2; HDR-M-2.54_1X2
JP1: HDR-M-2.54_1x3; HDR-M-2.54_1X3
L1, L2: 10uH; SRP2313AA
PWR1: 0436500201
PWR2: Mini-fit Jr; 0039301080
Pad_gge22614: Pad_gge22614
Pad_gge22653: Pad_gge22653
Pad_gge24533: Pad_gge24533
Pad_gge33304: Pad_gge33304
Q1, Q2, Q3, Q4: BSZ018N04LS6; PG-TSDSON-8_L3.3-W3.3-P0.65-BL
R1: 33k; R0603
R3: 4.7k; R0603
R4: 47k; R0805
R5, R7: 4.7; R0603
RSNS1, RSNS2: HCSK1216FT1L00; HCSK1216
TP1, TP2, TP3, TP4, TP5, TP6, TP7, TP10, TP11, TP12, TP13, TP14, TP15, TP16: Testpoint_Symbol; TP_TOUCH
U1: TPS7A2401DBVR; SOT-23-5_L2.9-W1.6-P0.95-LS2.8-BR
U2, U5: INA213AIDCKR; TSSOP-6_L2.0-W1.3-P0.65-LS2.0-BR
U3, U4: MP1909GTL-P; SOT-583-8_L2.1-W1.6-P0.50-LS1.6-BL

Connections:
A_OUT: CN1.1, RSNS1.2
A_OUT_FILT: C6.2, C8.2, C21.P, C22.P, C23.P, C24.2, C25.2, C26.2, C27.2, L1.2, RSNS1.1
A_SNS_HI: CN3_ALT.2, RSNS1.3, U2.5
A_SNS_LO: CN3_ALT.1, RSNS1.4, U2.4
B_OUT: CN2.1, RSNS2.1
B_OUT_FILT: C5.2, C7.2, C31.P, C32.P, C34.2, C35.2, C36.2, C37.2, C39.P, L2.2, RSNS2.2
B_SNS_HI: CN3_ALT.4, RSNS2.4, U5.4
B_SNS_LO: CN3_ALT.3, RSNS2.3, U5.5
C28_1: C28.1, R7.2
CN9_6: CN9.6, R4.1
DRVH_A: Q1.4, TP3.1, U3.8
DRVL_A: Q2.4, TP5.1, U3.5
GD_PWM_A: CN9.1, TP1.1, U3.2
GD_PWM_C: CN9.2, TP2.1, U4.2
GND: C1.1, C2.1, C3.1, C4.1, C5.1, C6.1, C7.1, C8.1, C9.N, C10.N, C11.N, C12.1, C13.1, C14.1, C15.1, C16.1, C17.1, C19.1, C20.1, C21.N, C22.N, C23.N, C24.1, C25.1, C26.1, C27.1, C29.1, C30.1, C31.N, C32.N, C33.1, C34.1, C35.1, C36.1, C37.1, C38.1, C39.N, C40.1, C41.1, C42.N, CN3.5, CN3.6, CN3.7, CN3_ALT.5, CN3_ALT.6, CN3_ALT.7, CN9.4, PWR1.2, PWR2.1, PWR2.2, PWR2.3, PWR2.4, Q2.1, Q2.2, Q2.3, Q4.1, Q4.2, Q4.3, R3.1, TP13.1, TP15.1, TP16.1, U1.2, U2.2, U3.6, U4.6, U5.2
HIGH_GATE_C: Q3.4, TP4.1, U4.8
I_SNS_A_OUT: CN3.2, U2.6
I_SNS_B_OUT: CN3.4, U5.6
I_SNS_REF_IN: CN3.3, TP10.1, U2.1, U5.1
I_SNS_VCC: C40.2, C41.2, JP1.2, U2.3, U5.3
I_SNS_VCC_IN: CN3.1, JP1.1
LOW_GATE_C: Q4.4, TP6.1, U4.5
PH_EN: CN9.3, TP7.1, U3.3, U4.3
R5_2: C18.1, R5.2
R7_1: R7.1, U4.1
REG_FB: R1.1, R3.2, U1.4
SW_A: C18.2, L1.1, Q1.1, Q1.2, Q1.3, Q2.5, Q2.6, Q2.7, Q2.8, Q2.9, U3.7
SW_C: C28.2, L2.1, Q3.1, Q3.2, Q3.3, Q4.5, Q4.6, Q4.7, Q4.8, Q4.9, U4.7
U3_1: R5.1, U3.1
VCC: C1.2, C2.2, J1.2, JP1.3, PWR1.1, TP12.1, U1.1, U1.3
VDD: C4.2, C9.P, C10.P, C11.P, C12.2, C13.2, C14.2, C15.2, C16.2, C17.2, C33.2, C38.2, C42.P, J1.1, PWR2.5, PWR2.6, PWR2.7, PWR2.8, Q1.5, Q1.6, Q1.7, Q1.8, Q1.9, Q3.5, Q3.6, Q3.7, Q3.8, Q3.9, TP14.1
V_GDRV: C3.2, C19.2, C20.2, C29.2, C30.2, R1.2, R4.2, TP11.1, U1.5, U3.4, U4.4

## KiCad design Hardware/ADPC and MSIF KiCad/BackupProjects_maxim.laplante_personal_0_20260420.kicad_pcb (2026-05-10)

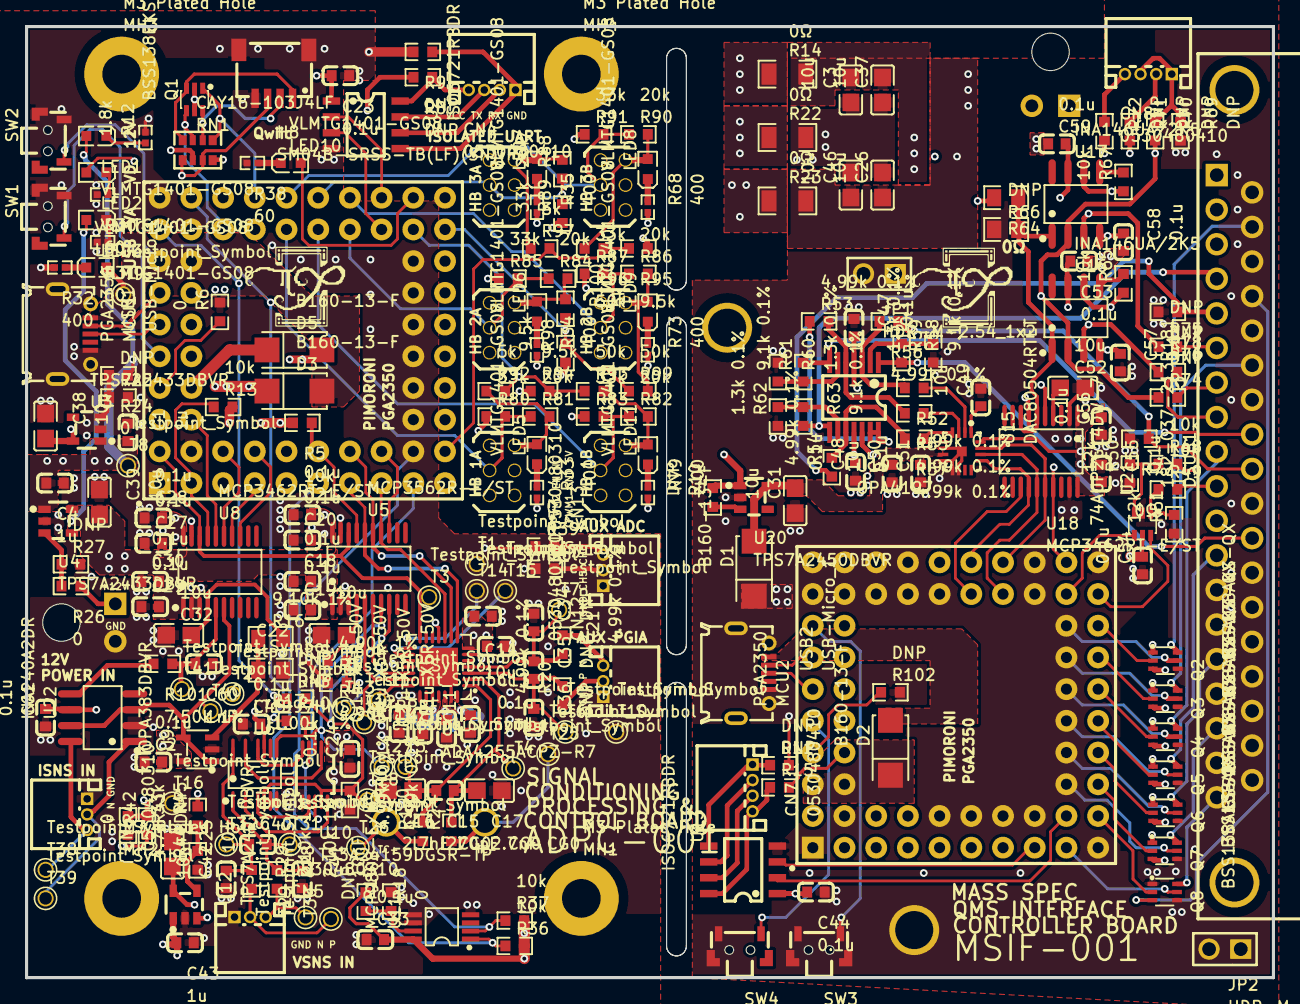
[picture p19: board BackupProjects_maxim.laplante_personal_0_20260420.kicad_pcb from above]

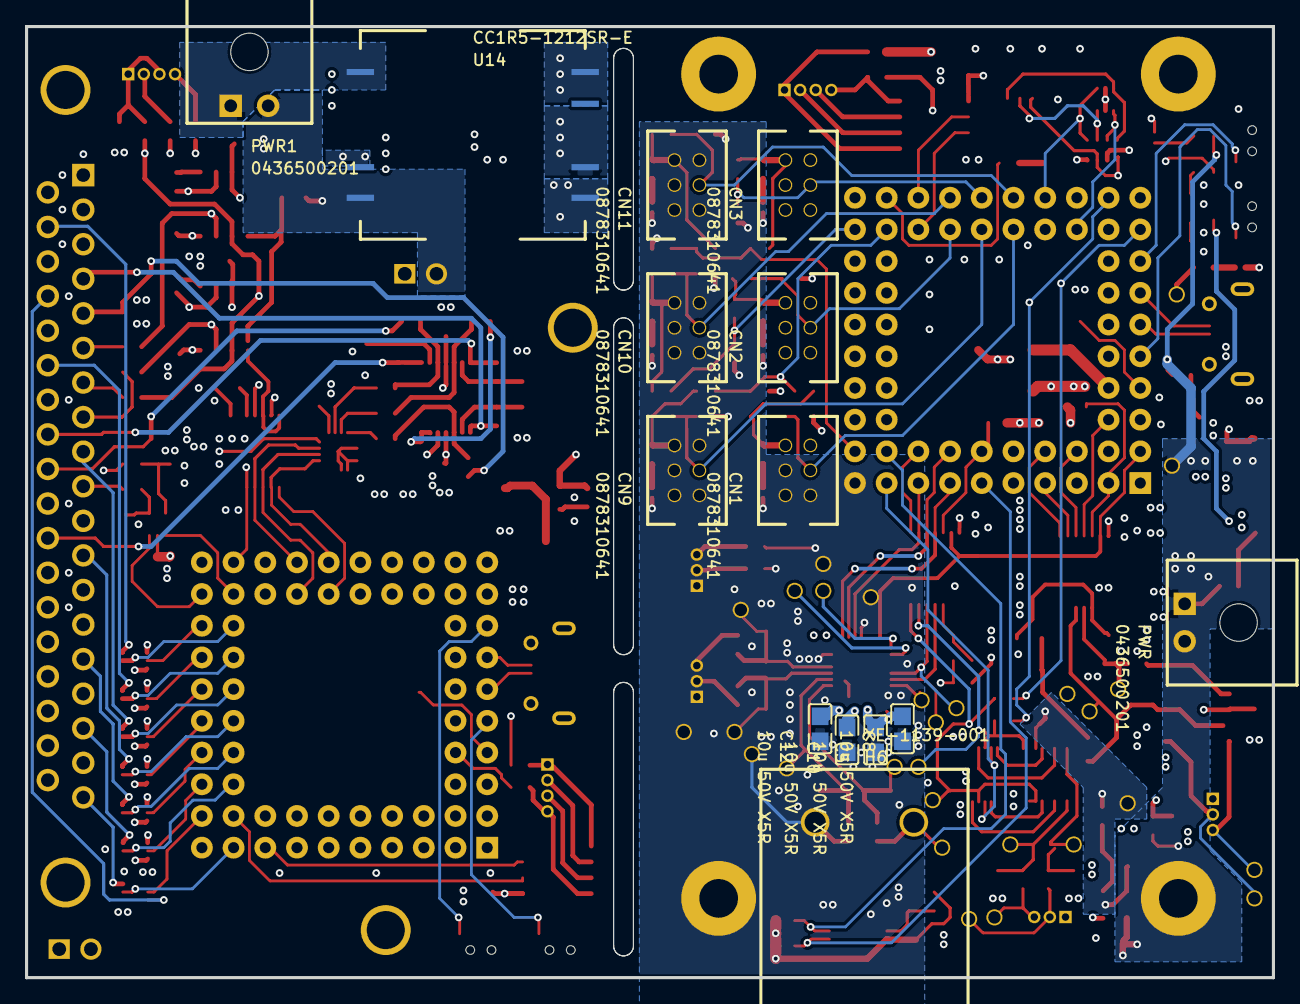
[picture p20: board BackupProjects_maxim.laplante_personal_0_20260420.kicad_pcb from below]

Board: 4 copper layers, 99.9 x 76.2 mm, 269 parts (14 on the bottom side), 217 nets.

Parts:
C1, C4, C43: 1u; C0603
C2, C13, C18, C19, C20, C21, C23, C24, C27, C28, C29, C30, C33, C44, C45, C47, C48, C51, C53, C54, C55, C56, C57, C58, C59, C61: 0.1u; C0603
C3, C25, C26, C31, C37, C38, C39, C46, C52: 10u; C0805
C5, C8, C10, C12: 10u 50V X5R; C0805
C6, C7, C9, C11: 0.1u X5R 50V; C0603
C14, C22, C32, C49, C50: 10u; C0603
C15: 270pF CG0; C0603
C16, C17: 2.7nF CG0; C0805
C34, C35, C36: DNP; C0603
C40, C60: 1nF; C0603
C41, C42: 10nF; C0603
CN1, CN2, CN3, CN9, CN10, CN11: 0878310641
CN4, CN7, CN8: 0530480410; CONN-TH_8P-P1.25_0530480610
CN5, CN6, CN12, CN13: 0530480310; CONN-TH_8P-P1.25_0530480410
D1, D2, D3, D5: B160-13-F; SMA_L4.3-W2.6-LS5.2-RD
DSUB1: 182-037-213R181; DB37-TH_182-037-213R181
H6: XE-1139-001; CONN-TH_XE-1139-001
H8: SM04B-SRSS-TB(LF)(SN)(P); CONN-SMD_4P-P1.00_SM04B-SRSS-TB-LF-SN
JP1, JP2: HDR-M-2.54_1x2; HDR-M-2.54_1X2
LED1, LED2, LED3, LED4, LED5, LED6, LED7, LED8, LED9, LED10, LED11: VLMTG1401-GS08; LED0603-RD_GREEN
MCU1, MCU2: PGA2350
MH1, MH2, MH3, MH4: M3 Plated Hole; M3 PLATED HOLE
PWR, PWR1: 0436500201
Pad_gge97344: Pad_gge97344
Pad_gge97365: Pad_gge97365
Q1: BSS138BKS,115; SOT-363_L2.0-W1.3-P0.65-LS2.1-BR
Q2, Q3, Q4, Q5, Q6, Q7, Q8: BSS138AKS-QX; SOT-363_L2.1-W1.3-P0.65-LS2.1-BL
R1, R2, R20, R21, R52, R53, R54, R55, R56, R57: 4.99k 0.1%; R0603
R3, R4: 4.90k 1%; R0603
R5, R13, R36, R37, R48, R49, R65, R67: 10k; R0603
R6, R18, R39, R47: 0; R0603_NEW
R8, R9, R11, R15, R19, R40, R43, R102: DNP; R0603_NEW
R10, R25, R27, R41, R69, R70, R71, R72, R74, R75, R76: DNP; R0603
R12: 1.8k; R0402
R14, R22, R23: 0Ω; R1206
R16: 9.10k 1%; R0805
R17: 1.00k 1%; R0805
R24, R26, R42, R46: 0; R0603
R28, R29: 2.10k 1%; R0603_NEW
R30, R31, R38: 60; R0402
R32, R33, R34, R35, R68, R73, R79: 400; R0402
R44: 4.7k; R0603
R45, R80, R83, R85, R87, R89, R91: 33k; R0603
R50, R51: 12k; R0603
R58, R61, R63: 9.1k 0.1%; R0603
R59, R60, R62: 1.3k 0.1%; R0603
R64: 0Ω; R0805_1
R66: DNP; R0805_1
R77, R78: 0Ω; R0603
R81, R82, R84, R86, R88, R90: 20k; R0603
R92, R97, R100: 5k; R0603
R93, R96, R99: 50k; R0603
R94, R95, R98: 9.5k; R0603
R101: 7.50k 1%; R0603_NEW
RN1: CAY16-103J4LF; RES-ARRAY-SMD_0603-8P-L3.2-W1.6-BL
SW1, SW2, SW3, SW4: TS24CA; SW-SMD_2P-TS24CA
T1, T2, T3, T4, T5, T6, T7, T8, T9, T10, T11, T12, T13, T14, T15, T16, T25, T26, T27, T28, T29, T30, T31, T32, T38, T39, T40, T41: Testpoint_Symbol; TESTPOINT_FOOTPRINT
U1: ADA4255ACPZ-R7; QFN-28_L5.0-W5.0-P0.50-TL-EP3.1
U2, U13: ISO6721RBDR; SOP-8_L4.9-W3.9-P1.27-LS6.0-BL_ISO6721RBDR
U3, U4: TPS7A2433DBVR; SOT-23-5_L2.9-W1.6-P0.95-LS2.8-BR
U5: MCP3562R-E/ST; TSSOP-20_L6.5-W4.4-P0.65-LS6.4-BL
U6: LT1997HMS-1#TRPBF; MSOP-16_12P-L4.0-W3.0-P0.50-LS4.9-BL
U8, U18: MCP3462RT-E/ST; TSSOP-20_L6.5-W4.4-P0.65-LS6.4-BL
U9: OPA383DBVR; SOT-23-5_L3.0-W1.7-P0.95-LS2.8-BL
U10: TS3A24159DGSR-TP; MSOP-10_L3.0-W3.0-P0.50-LS4.9-BL
U11: MCP9808-E/MS; MSOP-8_L3.0-W3.0-P0.65-LS4.9-BL
U12: TPS7A2401DBVR; SOT-23-5_L2.9-W1.6-P0.95-LS2.8-BR
U14: CC1R5-1212SR-E; CC1R5-E MODULE
U15: DAC80504RTET; WQFN-16_L3.0-W3.0-P0.50-TL-EP0.8
U16, U17: INA146UA/2K5; SOIC-8_L4.9-W3.9-P1.27-LS6.0-BL
U19: OPA4197; TSSOP-14_L5.0-W4.4-P0.65-LS6.4-BL
U20: TPS7A2450DBVR; SOT-23-5_L2.9-W1.6-P0.95-LS2.8-BR
U21: 74AUP2G14DW-7; SOT-363_L2.0-W1.3-P0.65-LS2.1-BR
U22: INA240A2DR; SOIC-8_L4.9-W3.9-P1.27-LS6.0-BL
USB1, USB2: USB-Micro_1; MICRO-USB-SMD_5P-P0.65-H-F_C10418

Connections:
3V3: C13.2, C14.2, C20.2, C21.2, C23.2, C24.2, C27.2, C28.2, C33.2, C38.2, D5.2, LED2.2, Q1.2, Q1.5, R5.2, R8.2, R13.2, R18.1, R36.2, R37.2, RN1.2, RN1.4, T1.1, U1.7, U2.1, U3.5, U5.20, U8.20, U10.1, U11.8
3V3A: C2.2, C5.2, C6.2, C7.2, C8.2, C18.2, C19.2, C29.2, C30.2, C39.2, C61.2, LED3.2, T2.1, U1.23, U1.25, U4.5, U5.1, U8.1, U9.5, U22.6
3V3_IF: C44.2, C54.2, C55.2, C56.2, MCU2.3V3, R15.2, U13.1, U15.16, U18.1, U18.20, U21.5
5V_IF: C31.2, C50.2, C51.2, D1.2, U15.7, U20.5
10V: C25.2, C45.2, R45.2, T16.1, U6.11, U12.5
10V_EN: R41.1, R42.2, U12.3
10V_FB: R44.2, R45.1, U12.4
12VIN: C1.2, C4.2, C43.2, LED1.2, PWR.1, R24.1, R26.1, R42.1, T8.1, U3.1, U4.1, U12.1
12VIN_MSIF: PWR1.1, U14.1
+12V_IF: C3.2, C37.2, C47.2, C53.2, C59.2, R10.2, R14.2, U16.7, U17.7, U19.4, U20.1
-12V_IF: C26.1, C46.1, C48.2, C57.1, C58.1, R23.2, U16.4, U17.4, U19.11
ADC_16_IRQ: MCU1.2, R13.1, U8.17
ADC_16_MCLK: MCU1.1, T3.1, U1.14, U5.18, U8.18
ADC_16_REFOUT: C32.2, R16.2, U8.4
ADC_16_SPI_CS: MCU1.5, U8.13
ADC_16_SPI_SCK: MCU1.6, U8.14
ADC_16_SPI_SDI: MCU1.3, U8.15
ADC_16_SPI_SDO: MCU1.0, U8.16
ADC_24_IRQ: MCU1.9, R5.1, U5.17
ADC_24_SPI_CS: MCU1.13, U5.13
ADC_CH0: T12.1, U1.20, U5.5
ADC_CH1: T13.1, U1.19, U5.6
ADC_REFOUT: C22.2, R4.2, U5.4
CN7_1: CN7.1, R11.1, U13.5
CN7_2: CN7.2, U13.6
CN7_3: CN7.3, U13.7
CN7_4: CN7.4, R15.1, U13.8
D1_1: D1.1, D2.1, MCU2.VBUS
DSUB1_6: DSUB1.6, R75.2
DSUB1_7: DSUB1.7, R74.2
DSUB1_8: DSUB1.8, R76.2
GND: C1.1, C2.1, C4.1, C5.1, C6.1, C7.1, C8.1, C9.1, C10.1, C11.1, C12.1, C13.1, C14.1, C16.2, C17.1, C18.1, C19.1, C20.1, C21.1, C22.1, C23.1, C24.1, C25.1, C27.1, C28.1, C29.1, C30.1, C32.1, C33.1, C34.1, C36.2, C38.1, C39.1, C41.2, C42.1, C43.1, C45.1, C60.1, C61.1, CN1.4, CN2.4, CN3.4, CN5.1, CN6.1, CN9.4, CN10.4, CN11.4, CN12.1, CN13.1, H8.4, H8.5, H8.6, MCU1.GND, PWR.2, R3.1, R6.2, R9.2, R12.2, R17.1, R19.2, R25.2, R27.2, R30.2, R31.2, R32.2, R33.2, R34.2, R35.2, R38.2, R41.2, R44.1, R46.2, R68.2, R73.2, R79.2, R80.1, R83.1, R85.1, R87.1, R89.1, R91.1, R94.1, R95.1, R98.1, SW1.2, SW1.3, SW2.2, SW2.3, T10.1, U1.6, U1.22, U2.4, U3.2, U4.2, U5.2, U5.3, U5.19, U6.8, U8.2, U8.3, U8.19, U9.2, U10.6, U11.4, U11.5, U11.6, U12.2, U22.2, USB1.5, USB1.SH0
GND_IN_MSIF: JP1.2, PWR1.2, U14.3
I2C_HEADER_SCL: MCU1.43, Q1.4, RN1.7
I2C_HEADER_SDA: MCU1.42, Q1.1, RN1.5
INAMP_GPIO2_CALIB_BUSY: MCU1.4, T15.1, U1.16
INAMP_GPIO3_FAULT: MCU1.8, T14.1, U1.15
INAMP_IN1_N: C15.1, C17.2, R2.2, T4.1, U1.2
INAMP_IN1_P: C15.2, C16.1, R1.2, T5.1, U1.1
INAMP_IN2_N: C34.2, C35.1, R21.2, T7.1, U1.4
INAMP_IN2_P: C35.2, C36.1, R20.2, T6.1, U1.3
INAMP_SPI_CS: MCU1.7, U1.11
INAMP_SPI_SCLK: MCU1.14, U1.10, U5.14
INAMP_SPI_SDI: MCU1.11, U1.9, U5.15
INAMP_SPI_SDO: MCU1.12, U1.8, U5.16
INAMP_VDDH: C9.2, C10.2, U1.26
INAMP_VOCM: R3.2, R4.1, T11.1, U1.21
INAMP_VSSH: C11.2, C12.2, U1.27, U1.29
INA_AUX_N: CN12.3, R21.1
INA_AUX_P: CN12.2, R20.1
ISOUART_RX: CN4.2, U2.6
ISOUART_TX: CN4.3, U2.7
I_AMP2_OUT_FILT: C60.2, R101.1, T41.1, U8.5
I_AMP_OUT: R101.2, U22.5
I_AMP_REF: T40.1, U8.6, U9.1, U9.4, U22.3, U22.7
LED1_1: LED1.1, R12.1
LED2_1: LED2.1, R30.1
LED3_1: LED3.1, R31.1
LED4_1: LED4.1, R32.1
LED5_1: LED5.1, R33.1
LED6_1: LED6.1, R34.1
LED7_1: LED7.1, R35.1
LED9_1: LED9.1, R73.1
LED10_1: LED10.1, R38.1
LED11_1: LED11.1, R79.1
MCU1_3V3EN: MCU1.3V3EN, R6.1
MCU1_BOOTSEL: MCU1.BOOTSEL, SW2.1
MCU1_RUN: MCU1.RUN, SW1.1
MCU2_3V3EN: MCU2.3V3EN, R102.1
MCU2_BOOTSEL: MCU2.BOOTSEL, SW3.1
MCU2_RUN: MCU2.RUN, SW4.1
MCU2_USB+: MCU2.USB+, USB2.3
MCU2_USB-: MCU2.USB-, USB2.2
MCU_3V3: D5.1, MCU1.3V3
MCU_ADC_5: MCU1.45, R40.1, R47.1
MCU_ADC_6: MCU1.46, R39.1, R43.1
MCU_INDICATOR_LED_1: LED10.2, MCU1.32
MCU_VBUS: D3.1, MCU1.VBUS
MH: DSUB1.38, DSUB1.39, MH1.1, MH2.1, MH3.1, MH4.1
MPHB_5V_1: CN1.6, LED5.2, R81.2, R92.1
MPHB_5V_1.1: CN9.6, LED11.2, R82.2, R93.2
MPHB_5V_2: CN2.6, LED6.2, R84.2, R100.1
MPHB_5V_2.1: CN10.6, LED9.2, R86.2, R99.2
MPHB_5V_3: CN3.6, LED7.2, R88.2, R97.1
MPHB_5V_3.1: CN11.6, LED8.2, R90.2, R96.2
MPHB_ISNS_N: CN6.2, T39.1, U22.1
MPHB_ISNS_P: CN6.3, T38.1, U22.8
MPHB_VDET_1: MCU1.31, R92.2, R93.1, R94.2
MPHB_VDET_2: MCU1.30, R98.2, R99.1, R100.2
MPHB_VDET_3: MCU1.17, R95.2, R96.1, R97.2
MPHB_VSNS_HI: CN5.3, R28.2, T29.1
MPHB_VSNS_LO: CN5.2, R29.2, T30.1
MSIF_ADC_CS: MCU2.37, U18.13
MSIF_ADC_IRQ: MCU2.32, U18.17
MSIF_ADC_SCK: MCU2.38, U15.13, U18.14
MSIF_AMP_EC: R65.1, U16.6, U18.5
MSIF_AMP_SCAN+: R67.1, U17.6, U18.7
MSIF_CLR_EC: MCU2.24, Q4.2
MSIF_DAC_REFO: C49.1, U15.1
MSIF_DAC_SDI: MCU2.35, U15.14, U18.15
MSIF_DAC_SDO: MCU2.36, U15.15, U18.16
MSIF_DAMP_REF: R64.1, R66.2, U16.1, U17.1, U18.6, U18.8
MSIF_EMIS_OK: MCU2.30, U21.6
MSIF_FMASS: R52.1, U15.2
MSIF_GAIN_0: MCU2.19, Q7.5
MSIF_GAIN_1: MCU2.18, Q7.2
MSIF_MODE_0: MCU2.21, Q6.5
MSIF_MODE_1: MCU2.20, Q6.2
MSIF_MODE_2: MCU2.23, Q5.5
MSIF_ON_LINE: MCU2.16, Q8.5
MSIF_RANGE_0: MCU2.22, Q5.2
MSIF_RANGE_1: MCU2.25, Q4.5
MSIF_RESET_SCAN: MCU2.26, Q3.2
MSIF_SCAN_IN_PROGRESS: MCU2.31, U21.4
MSIF_SEM: R57.1, U15.4
MSIF_SPEED_0: MCU2.27, Q3.5
MSIF_SPEED_1: MCU2.28, Q2.2
MSIF_SPEED_2: MCU2.29, Q2.5
MSIF_SPEED_3: MCU2.17, Q8.2
MSIF_SWIDTH: R55.1, U15.3
MSIF_UART_RX: MCU2.15, U13.2
MSIF_UART_TX: MCU2.14, U13.3
MSQDP_CLR_EC: DSUB1.9, Q4.6
MSQDP_DIG_GND: DSUB1.33, JP2.1
MSQDP_EC+: R71.2, R75.1, U17.3
MSQDP_EC-: R70.2, R74.1, U16.2, U17.2, U19.12
MSQDP_EC-_BUFF: R53.1, R64.2, U19.13, U19.14
MSQDP_EMIS_OK: DSUB1.10, R49.2
MSQDP_FMASS+: DSUB1.30, R58.2, U19.1
MSQDP_FMASS-: DSUB1.28, R56.1, R77.1
MSQDP_GAIN_0: DSUB1.18, Q7.3
MSQDP_GAIN_1: DSUB1.17, Q7.6
MSQDP_MODE_0: DSUB1.16, Q6.3
MSQDP_MODE_1: DSUB1.15, Q6.6
MSQDP_MODE_2: DSUB1.14, Q5.3
MSQDP_ON_LINE: DSUB1.23, Q8.3
MSQDP_RANGE_0: DSUB1.12, Q5.6
MSQDP_RANGE_1: DSUB1.11, Q4.3
MSQDP_RESET_SCAN: DSUB1.25, Q3.6
MSQDP_SCAN+: R72.2, R76.1, U16.3
MSQDP_SCAN_IN_PROGRESS: DSUB1.24, R48.2
MSQDP_SEM+: DSUB1.4, R63.2, U19.8
MSQDP_SEM-: DSUB1.5, R54.1, R78.1
MSQDP_SIG_GND: C3.1, C26.2, C31.1, C37.1, C44.1, C46.2, C47.1, C48.1, C49.2, C50.1, C51.1, C52.2, C53.1, C54.1, C55.1, C56.1, C57.2, C58.2, C59.1, DSUB1.26, JP2.2, MCU2.GND, Q2.1, Q2.4, Q3.1, Q3.4, Q4.1, Q4.4, Q5.1, Q5.4, Q6.1, Q6.4, Q7.1, Q7.4, Q8.1, Q8.4, R11.2, R22.2, R50.1, R51.1, R59.1, R60.1, R62.1, R66.1, R69.2, R77.2, R78.2, R102.2, SW3.2, SW3.3, SW4.2, SW4.3, U13.4, U15.6, U15.8, U15.9, U15.10, U15.17, U18.2, U18.19, U20.2, U21.2, USB2.5, USB2.SH0
MSQDP_SPEED_0: DSUB1.22, Q3.3
MSQDP_SPEED_1: DSUB1.21, Q2.6
MSQDP_SPEED_2: DSUB1.20, Q2.3
MSQDP_SPEED_3: DSUB1.19, Q8.6
MSQDP_SWIDTH+: DSUB1.27, R61.2, U19.7
PH_EN_A1: CN1.3, MCU1.39, R80.2, R81.1
PH_EN_A2: CN2.3, MCU1.35, R84.1, R85.2
PH_EN_A3: CN3.3, MCU1.38, R88.1, R89.2
PH_EN_B1: CN9.3, MCU1.37, R82.1, R83.2
PH_EN_B2: CN10.3, MCU1.36, R86.1, R87.2
PH_EN_B3: CN11.3, MCU1.40, R90.1, R91.2
PWM_A_1: CN1.2, MCU1.18
PWM_A_2: CN2.2, MCU1.23
PWM_A_3: CN3.2, MCU1.28
PWM_B_1: CN9.2, MCU1.20
PWM_B_2: CN10.2, MCU1.25
PWM_B_3: CN11.2, MCU1.26
PWM_C_1: CN1.1, MCU1.19
PWM_C_2: CN2.1, MCU1.22
PWM_C_3: CN3.1, MCU1.29
PWM_D_1: CN9.1, MCU1.21
PWM_D_2: CN10.1, MCU1.24
PWM_D_3: CN11.1, MCU1.27
QT_SCL: H8.1, Q1.3, RN1.8
QT_SDA: H8.2, Q1.6, RN1.6
QT_VCC: H8.3, RN1.1, RN1.3
R16_1: R16.1, R17.2, U9.3
R39_2: CN13.3, R39.2
R47_2: CN13.2, R47.2
R52_2: R52.2, R56.2, U19.3
R55_2: R53.2, R55.2, U19.5
R57_2: R54.2, R57.2, U19.10
R68_1: LED8.1, R68.1
R69_1: CN8.1, CN8.3, R69.1, R70.1
R71_1: CN8.2, R71.1
R72_1: CN8.4, R72.1
TC_N: H6.2, R2.1, T25.1
TC_P: H6.1, R1.1, T26.1
TMP_I2C_SCL: MCU1.15, R37.1, U11.2
TMP_I2C_SDA: MCU1.10, R36.1, U11.1
U2_5: CN4.1, R9.1, U2.5
U2_8: CN4.4, R8.1, U2.8
U3_3: R24.2, R25.1, U3.3
U4_3: R26.2, R27.1, U4.3
U11_7: R18.2, R19.1, U11.7
U14_2: JP1.1, U14.2
U14_4: R23.1, U14.4
U14_5: R22.1, U14.5
U14_7: R14.1, U14.7
U16_5: R65.2, U16.5
U17_5: R67.2, U17.5
U18_4: C52.1, U18.4
U19_2: R58.1, R59.2, U19.2
U19_6: R60.2, R61.1, U19.6
U19_9: R62.2, R63.1, U19.9
U20_3: R10.1, U20.3
U21_1: R49.1, R51.2, U21.1
U21_3: R48.1, R50.2, U21.3
UART_RX: MCU1.33, U2.3
UART_TX: MCU1.34, U2.2
USB2_1: D2.2, USB2.1
USB_D+: MCU1.USB+, USB1.3
USB_D-: MCU1.USB-, USB1.2
VSNS_AMP_3K_N: U6.12, U10.5
VSNS_AMP_3K_P: U6.5, U10.7
VSNS_AMP_7K5_N: U6.14, U10.2
VSNS_AMP_7K5_P: U6.3, U10.10
VSNS_AMP_GAIN_SEL: MCU1.16, U10.4, U10.8
VSNS_AMP_OUT: R40.2, T27.1, U5.7, U6.9, U10.3
VSNS_AMP_REF: R43.2, R46.1, T28.1, U5.8, U6.6, U6.7, U10.9
VSNS_FILT_N: C40.1, C42.2, R29.1, T32.1, U6.16
VSNS_FILT_P: C40.2, C41.1, R28.1, T31.1, U6.1
V_USB: D3.2, LED4.2, T9.1, USB1.1

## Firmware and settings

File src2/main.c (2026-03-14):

#include <stdio.h>
#include <stdlib.h>
#include <stdint.h>

#include "pico/stdlib.h"
#include "pico/bootrom.h"

#include "hardware/adc.h"
#include "hardware/dma.h"
#include "hardware/pwm.h"
#include "hardware/i2c.h"
#include "hardware/clocks.h"
#include "pico/multicore.h"

#include "capstone_pwm.h"
#include "capstone_dsp.h"
#include "capstone_adc.h"
#include "capstone_thermocouple.h"
#include "capstone_w25.h"
#include "capstone_measurement_routines.h"


#define PMIC_I2C_SDA_PIN 8
#define PMIC_I2C_SCL_PIN 9
#define PMIC_I2C i2c0
#define PMIC_I2C_TIMEOUT_US 10000

#define NA_ADC_PIN 26

#define PWMTOOL_GPIO_PIN 7

#define UI_SIG_ICTL_START_STOP 0xBEEF
#define UI_SIG_NA_START_STOP 0xABCD
#define UI_SIG_CURRENT_CONTROLLER_PAUSE_UNPAUSE 0xFACE
#define UI_SIG_PWM_INC 0xBABB
#define UI_SIG_PWM_DEC 0xBABA
#define UI_SIG_PWM_START_STOP 0xBAAA
#define UI_SIG_PWM_READ_ISNS 0xBAAB

mutex_t current_controller_lock;
volatile PI_controller_t current_controller;

volatile capstone_adc_struct_t *cas;
volatile uint16_t *TSNS_ADC_value_12_bit_avg, *ISNS_ADC_value_12_bit_avg, *dutycycle_datalog, *T_datalog;
volatile uint16_t T_glob = 0;
volatile uint32_t VTCMV_glob = 0;

int32_t INA236_read_bus_voltage() {
    //printf("Reading INA236 Bus Voltage...\n");
    uint8_t INA236B_msg[1] = {0x2};
    uint8_t INA236_read_dst[2];
    int i2cret = i2c_write_timeout_us(i2c0, 0x48, INA236B_msg, 1, 1, PMIC_I2C_TIMEOUT_US);
    if(i2cret != 1) return -1000;
    i2cret = i2c_read_timeout_us(i2c0,0x48,INA236_read_dst,2,0,PMIC_I2C_TIMEOUT_US);
    if(i2cret != 2) return -2000;
    //printf("Read values: 0x%02X%02X\n",INA236_read_dst[0],INA236_read_dst[1]);
    //printf("ADC value: %d\n",((int16_t)INA236_read_dst[0] << 8) | ((int16_t)INA236_read_dst[1]));
    return ((int16_t)INA236_read_dst[0] << 8) | ((int16_t)INA236_read_dst[1]);
}

#define DATALOGGING_BASE_ADDR 0x11000
// multicore datalogging signal flag
#define MC_DL_TRIG 0xBEEF0000
#define MC_DL_FLAG_MASK 0xFFFF0000
#define MC_DL_BUFF_I_MASK 0x0000FFFF
volatile int datalogger_q_w = 0;
int datalogger_q_r = 0;
int datalogging_pages_written = 0;
int datalogging_waddr = DATALOGGING_BASE_ADDR;


void isns_dma_handler() {
    static int counter = 0;
    static int d = 100;
    //debugging toggle
    sio_hw->gpio_togl = 0x1<<18;
    // if the second [1] of the DMAs has triggered an interrupt, we can probably assume (DANGEROUS) that we should look halfway through the buffer.
    int data_offset = (ADC_BUFFER_SIZE / 2) * (int) dma_channel_get_irq0_status(cas->adc_dma_daisy_chain[1]);
    // this shouldn't produce a branch... I think?
    int culprit_dma_daisy_chain_index = (data_offset != 0);
    uint16_t *data = &(cas->adc_dma_buffer[data_offset]);
    // a little stupid, but set the write address to where we starting getting data from.
    // TODO: configure the DMAs as wrapping rings so that they don't need to be reset. or use a third, cleanup DMA
    (cas->adc_dma_daisy_chain_hw[culprit_dma_daisy_chain_index])->write_addr = (uintptr_t)(data);

    // so-called DSP:
    int isns_avg = 0;
    for(int i = 0; i<ADC_BUFFER_SIZE/4; i++) isns_avg+= data[2*i];
    // multiply the isns avg by eight, the PI_SP resolution (while dividing for averaging)
    isns_avg >>= 3;

    int tsns_avg = 0;
    for(int i = 0; i<ADC_BUFFER_SIZE/4; i++) tsns_avg += data[2*i + 1];
    // divide by 64
    tsns_avg >>= 6;


    // every fourth DSP IRQ should log a "sample" (x2ch)
    if(((++counter)&0x3) == 0) {
        TSNS_ADC_value_12_bit_avg[datalogger_q_w] = tsns_avg;
        ISNS_ADC_value_12_bit_avg[datalogger_q_w] = isns_avg;
        dutycycle_datalog[datalogger_q_w] = d;
        T_datalog[datalogger_q_w] = T_glob;
        //                                                  DATALOGGING
        // round-robin buffer/queue
        // TRIGGER every 64 samples (128 bytes x 3ch = 384bytes = 1.5 pages)
        // WRAP every 128 samples
        if ((datalogger_q_w & 63) == 63) {
            //non-blocking signal to push. TODO: if a data-log multicore push *doesn't* happen, there's no timestamp correction.
            if (multicore_fifo_wready()) {
                multicore_fifo_push_blocking(MC_DL_TRIG | (MC_DL_BUFF_I_MASK&(datalogger_q_w-63)));
            }
        }
        datalogger_q_w++;
        datalogger_q_w &= 127;
    }

    // BEST FIT LINE FROM XY PLOT
    // Vin =  -214.2785663 * Vdiff + 2.908868568
    // ADC to Vtc_mv_4092:
    // Vtc,mv,4092 = -ADCval * 3300/214.28 + 2908.9 * 4092 / 204
    // 15.4005 and 58,348.5
    // 15.4005 = 1,971.264 / 128 ... 1971 / 128 = 15.3984375
    uint32_t vtc_mv_4092 = 58349 - ((tsns_avg * 1971)>>7);
    VTCMV_glob = vtc_mv_4092;
    vtc_mv_4092 += ktype_voltages_20C_x4092[2];
    uint16_t T = 0;
    for(T = 0; T < ktype_voltages_len; T++) {
        if(ktype_voltages_20C_x4092[T] >= vtc_mv_4092) {
            T_glob = T+20;
            int Tstepsize = ktype_voltages_20C_x4092[T] - ktype_voltages_20C_x4092[T-1];
            int Tdiff = ktype_voltages_20C_x4092[T] - vtc_mv_4092;
            T_glob = (T_glob*8) - ((8*Tdiff)/Tstepsize); // T_glob is eight times the actual temperature, with a resolution of 0.125degC
            break;
        }
    }


    // psuedo-integral control. Increment faster for bigger errors.
    // Don't change the duty cycle if the controller is paused.
    if(!current_controller.controller_paused) {
        //          OLD GAIN VALUE WITH G=100
        // 62 = 4096 * 0.05 / 3.3
        // 15.5 = 62 / 4 since we want that kind of resolution on our PISP
        //          NEW GAIN VALUE WITH G=150
        // 4096 * 0.0005 * 150 / 3.3 = 93.1
        // 23.75 ≈ 24 = 93.1 / 4 as per above resolution comment
        //      260204      NEW GAIN VALUE WITH G=40
        //          NEW GAIN VALUE WITH G=50 (47.8)
        // 4096 * 0.0005 * 47.8 / 3.3 = 29.66
        // Since our PI_SP resolution is 1/8 amps (i.e. +1 PI_SP = +0.125A), we are
        // multiplying our isns_avg by eight in our "averaging" function
        int targ = current_controller.PI_SP * 30;
        d += -(isns_avg > targ) + (isns_avg < targ) - 2 * (isns_avg + 16 > targ) - 2 * (isns_avg + 32 > targ);
        if(d>380) d= 380;
        if(d<90) d= 90;
        pwm_set_gpio_level(PWM2_GPIO_PIN,d);
        pwm_set_gpio_level(PWM4_GPIO_PIN,d);
        pwm_set_gpio_level(PWM6_GPIO_PIN,d);
        pwm_set_gpio_level(PWM8_GPIO_PIN,d);
    
    }


    // clear the correct interrupt
    dma_hw->ints0 = 0x1 << cas->adc_dma_daisy_chain[culprit_dma_daisy_chain_index];
    // debugging toggler
    sio_hw->gpio_togl = 0x1<<18;
}

void other_core() {
    multicore_fifo_push_blocking(UI_SIG_ICTL_START_STOP);
    printf("MULTICORE EXPLOSION!!!\n");

    cas = (capstone_adc_struct_t *)malloc(sizeof(capstone_adc_struct_t));
    capstone_adc_init(cas, isns_dma_handler);
    mutex_init(&current_controller_lock);

    //note: most of this functionality is deprecated and unused and need to be updated.
    // TODO: rewrite current control code so it is modular.
    PI_controller_init(&current_controller,
                       10,
                       569,
                       9,
                       27314,
                       440,
                       500000000,
                       110,
                       250
    );

    gpio_init(18);
    gpio_set_dir(18,GPIO_OUT);
    gpio_pull_up(18);
    gpio_set_slew_rate(18,GPIO_SLEW_RATE_FAST);


    sleep_ms(100);
    int ui = 0;
    while(1) {
        ui = multicore_fifo_pop_blocking();
        if(ui == UI_SIG_ICTL_START_STOP) {

            printf("[CL control started. Press 'r' to see status, press the spacebar to pause.]\n");
            pwm_set_gpio_level(PWM1_GPIO_PIN, 100);
            pwm_set_gpio_level(PWM2_GPIO_PIN, 100);
            pwm_set_gpio_level(PWM3_GPIO_PIN, 100);
            pwm_set_gpio_level(PWM4_GPIO_PIN, 100);
            pwm_set_gpio_level(PWM5_GPIO_PIN, 100);
            pwm_set_gpio_level(PWM6_GPIO_PIN, 100);
            pwm_set_gpio_level(PWM7_GPIO_PIN, 100);
            pwm_set_gpio_level(PWM8_GPIO_PIN, 100);

            capstone_adc_start(cas);

            while (1) {
                uint32_t sig = multicore_fifo_pop_blocking();
                if (sig == UI_SIG_ICTL_START_STOP) {
                    break;
                }
                else {
                    if (mutex_try_enter(&current_controller_lock, NULL)) {
                        if (sig == UI_SIG_CURRENT_CONTROLLER_PAUSE_UNPAUSE) {
                            current_controller.controller_paused = !current_controller.controller_paused;
                            printf("%s\n", current_controller.controller_paused ? "PAUSED" : "RESUMED");
                        } else {
                            current_controller.PI_SP = sig;
                            printf("\tPISP %d\n", current_controller.PI_SP);
                        }
                        mutex_exit(&current_controller_lock);
                    } else printf("MUTEX LOCKED\n");
                }
            }

            printf("[CL control paused, all outputs to 0]\n");
            capstone_adc_stop(cas);
            multicore_fifo_drain();

            pwm_set_gpio_level(PWM1_GPIO_PIN, 0);
            pwm_set_gpio_level(PWM2_GPIO_PIN, 0);
            pwm_set_gpio_level(PWM3_GPIO_PIN, 0);
            pwm_set_gpio_level(PWM4_GPIO_PIN, 0);
            pwm_set_gpio_level(PWM5_GPIO_PIN, 0);
            pwm_set_gpio_level(PWM6_GPIO_PIN, 0);
            pwm_set_gpio_level(PWM7_GPIO_PIN, 0);
            pwm_set_gpio_level(PWM8_GPIO_PIN, 0);
        }
        else if(ui == UI_SIG_NA_START_STOP) {
            network_analyzer_slave_start();
            while (1) {
                uint32_t sig = multicore_fifo_pop_blocking();
                if (sig == UI_SIG_NA_START_STOP) break;
                //current_controller.PI_SP = sig;
            }
            network_analyzer_slave_stop();
        }
        else if(ui == UI_SIG_PWM_START_STOP) {
            uint16_t pwm_lvl = 100;
            printf("[PWM started. Press 'r' to see status, press the spacebar to pause.]\n");
            pwm_set_gpio_level(PWM1_GPIO_PIN, 100);
            pwm_set_gpio_level(PWM2_GPIO_PIN, pwm_lvl);
            pwm_set_gpio_level(PWM3_GPIO_PIN, 100);
            pwm_set_gpio_level(PWM4_GPIO_PIN, pwm_lvl);
            pwm_set_gpio_level(PWM5_GPIO_PIN, 100);
            pwm_set_gpio_level(PWM6_GPIO_PIN, pwm_lvl);
            pwm_set_gpio_level(PWM7_GPIO_PIN, 100);
            pwm_set_gpio_level(PWM8_GPIO_PIN, pwm_lvl);

            adc_select_input(ISNS_ADC_PIN - 26);
            while (1) {
                uint32_t sig = multicore_fifo_pop_blocking();
                if (sig == UI_SIG_PWM_START_STOP) break;
                else if(sig == UI_SIG_PWM_READ_ISNS) {
                    uint16_t val = adc_read();
                    float valamps = (float)val/93.1;
                    printf("ADC %04d\t%2.1f\t",val,valamps);
                    val = adc_read();
                    valamps = (float)val/93.1;
                    printf("ADC %04d\t%2.1f\n",val,valamps);
                    continue;
                }
                else if(sig == UI_SIG_PWM_INC) pwm_lvl += 10;
                else if(sig == UI_SIG_PWM_DEC) pwm_lvl -= 10;
                else if(sig <= 9) pwm_lvl = sig*50 + 100;
                pwm_set_gpio_level(PWM2_GPIO_PIN, pwm_lvl);
                pwm_set_gpio_level(PWM4_GPIO_PIN, pwm_lvl);
                pwm_set_gpio_level(PWM6_GPIO_PIN, pwm_lvl);
                pwm_set_gpio_level(PWM8_GPIO_PIN, pwm_lvl);
                printf("\tPWM %d\n",pwm_lvl);
            }
            multicore_fifo_drain();
            printf("[PWM paused, all outputs to 0]\n");

            pwm_set_gpio_level(PWM1_GPIO_PIN, 0);
            pwm_set_gpio_level(PWM2_GPIO_PIN, 0);
            pwm_set_gpio_level(PWM3_GPIO_PIN, 0);
            pwm_set_gpio_level(PWM4_GPIO_PIN, 0);
            pwm_set_gpio_level(PWM5_GPIO_PIN, 0);
            pwm_set_gpio_level(PWM6_GPIO_PIN, 0);
            pwm_set_gpio_level(PWM7_GPIO_PIN, 0);
            pwm_set_gpio_level(PWM8_GPIO_PIN, 0);
        }
        else if(ui == 0xDEAD) {
            vtc_offset_sweep();
        }
    }

}

int main(void) {
                        /*** INITS ***/
    stdio_init_all();
    sleep_ms(1000);

    multicore_launch_core1(other_core);
    sleep_ms(1000);
    multicore_fifo_pop_blocking();

    capstone_pwm_init();
    printf("Hello Capstone World!\n");
//
//    i2c_init(i2c_default, 100 * 1000);
//    gpio_set_function(PMIC_I2C_SDA_PIN, GPIO_FUNC_I2C);
//    gpio_set_function(PMIC_I2C_SCL_PIN, GPIO_FUNC_I2C);
//    gpio_pull_up(PMIC_I2C_SDA_PIN);
//    gpio_pull_up(PMIC_I2C_SCL_PIN);

    W25_Init();

    TSNS_ADC_value_12_bit_avg = (uint16_t *)malloc(sizeof(uint16_t) * 256);
    ISNS_ADC_value_12_bit_avg = (uint16_t *)malloc(sizeof(uint16_t) * 256);
    dutycycle_datalog = (uint16_t *)malloc(sizeof(uint16_t) * 256);
    T_datalog = (uint16_t *)malloc(sizeof(uint16_t) * 256);

    uint32_t datalogger_q_r_cached = 0;

    if(TSNS_ADC_value_12_bit_avg == NULL || ISNS_ADC_value_12_bit_avg == NULL) {
        sleep_ms(10000);
        printf("BAD MALLOC ON DLBUFFS\n");
        goto reboot;
    }

    char ui = 0;
    int ict_latch = 0;
    int pwm_latch = 0;
    int pi_en_latch = 0;
    int D1_thresh = 10;
    int D1_thresh_setting_multiplier = 2;
    int PI_setpoint = 10;
    int ictl_zero_latch = 0;

    while(1) {
        int uii = stdio_getchar_timeout_us(100);
        if(uii != PICO_ERROR_TIMEOUT) {
            ui = (char)uii;
            // QUIT
            if (ui == 'q') break;
            // HELP MENU
            if (ui == 'h') {
                printf("\t\t[HELP MENU]\n"
                       "s: read Flash\n"
                       "m: change multiplier\n"
                       "0-9: set target current or pwm\n"
                       "/: toggle target current"
                       "p & l: inc/dec target current\n"
                       "i: test INA236 writing\n"
                       "u: dep\n"
                       "v: read INA236 bus voltage\n"
                       "space: start/stop PWM output\n"
                       "k: start/stop PI control\n"
                       "g: use with network analyzer\n"
                       "c: perform voffset sweep (dep)\n"
                       "t: read out temperature conversion\n"
                       "j: direct PWM control\n"
                       "r: read raw ISNS ADC value (PWM mode)\n"
                       "spacebar: current controller\n"
                       "\n\n"
                );
            }
            if (ui == 's') {
                if (ict_latch) {
                    printf("[REJECTED] Stop collection to read.\n");
                    continue;
                }
                //round up
                datalogging_pages_written = (datalogging_waddr-DATALOGGING_BASE_ADDR+W25_PAGE_SIZE-1)/256;
                printf("Number of pages written: %d\n", datalogging_pages_written);
                uint8_t *rx_buff = (uint8_t *) malloc(sizeof(uint8_t) * 256);
                if(rx_buff == NULL) {
                    printf("MALLOC FAILED!!\n\n");
                    goto reboot;
                }
                for (int i = 0; i < datalogging_pages_written; i++) {
                    printf("Page %d (0x%08X)\n", i, DATALOGGING_BASE_ADDR | (i << 8));
                    for (int i = 0; i < 256; i++) rx_buff[i] = 0;
                    W25_Read_Data(DATALOGGING_BASE_ADDR | (i << 8), rx_buff, W25_PAGE_SIZE);
                    uint16_t *rx_data = (uint16_t *) rx_buff;
                    for (int i = 0; i < W25_PAGE_SIZE/2; i++) {
                        if (rx_data[i] == 0xFFFF) printf("ND ");
                        else printf("%04X ", rx_data[i]);
                        if (!((i + 1) & 0xF)) printf("\n");
                    }
                    printf("\n");
                }
                free(rx_buff);

            }
            if (ui == 'm') {
                if ((++D1_thresh_setting_multiplier) > 24) D1_thresh_setting_multiplier = 1;
                printf("MULTIPLIER SET TO %d\n", D1_thresh_setting_multiplier);
            }
            if (ui == 'M') {
                if ((--D1_thresh_setting_multiplier) < 1) D1_thresh_setting_multiplier = 24;
                printf("MULTIPLIER SET TO %d\n", D1_thresh_setting_multiplier);
            }
            if (ui >= '0' && ui <= '9') {
                if (pwm_latch) {
                    // push the int value entered from 0 to 9
                    multicore_fifo_push_blocking((uint32_t) (ui) - '0');
                    continue;
                }
                PI_setpoint = 4 * ((uint16_t) ui - '0') * D1_thresh_setting_multiplier;
                printf("PI setpoint: %.3fA\n", PI_setpoint / 8.0);
                if (ict_latch & !ictl_zero_latch) {
                    multicore_fifo_push_blocking(PI_setpoint);
                }
            }
            if (ui == '/') {
                if (ict_latch) {
                    if(!ictl_zero_latch) {
                        ictl_zero_latch = !ictl_zero_latch;
                        multicore_fifo_push_blocking(0);
                        printf("[Paused output current; press '/' to resume]\n");
                    }
                    else {
                        ictl_zero_latch = !ictl_zero_latch;
                        multicore_fifo_push_blocking(PI_setpoint);
                        printf("[Resumed output current at  %.3fA]\n",PI_setpoint / 8.0);
                    }
                }
            }
            if (ui == 'p' || ui == 'l') {
                if (pwm_latch) {
                    if (ui == 'p') multicore_fifo_push_blocking(UI_SIG_PWM_INC);
                    if (ui == 'l') multicore_fifo_push_blocking(UI_SIG_PWM_DEC);
                }
                else {
                    if (ui == 'p') PI_setpoint += D1_thresh_setting_multiplier / 2;
                    if (ui == 'l') PI_setpoint += -D1_thresh_setting_multiplier / 2;
                    printf("PI setpoint: %.3fA\n", PI_setpoint / 8.0);
                    if (ict_latch && !ictl_zero_latch) {
                        multicore_fifo_push_blocking(PI_setpoint);
                    }
                }
            }
            if (ui == ' ' && !pwm_latch) {
                ict_latch = !ict_latch;
                multicore_fifo_push_blocking(UI_SIG_ICTL_START_STOP);
                multicore_fifo_push_blocking(PI_setpoint);
            }
            if (ui == 'j' && !ict_latch) {
                pwm_latch = !pwm_latch;
                multicore_fifo_push_blocking(UI_SIG_PWM_START_STOP);
            }
            if (ui == 'r' && pwm_latch) multicore_fifo_push_blocking(UI_SIG_PWM_READ_ISNS);
            if (ui == 'k' && ict_latch) {
                multicore_fifo_push_blocking(UI_SIG_CURRENT_CONTROLLER_PAUSE_UNPAUSE);
            }
            if (ui == 'g') {
                multicore_fifo_push_blocking(UI_SIG_NA_START_STOP);
            }
            if (ui == 'c') {
                //multicore_fifo_push_blocking(0xDEAD);
            }
            if (ui == 't') {
                if(datalogger_q_r_cached == 0) continue; // ignore the command if we haven't populated enough data.
                printf("Temp: %.3f\tRamp Rate: %.3f ºK/s\tADC: %d\tVtc_mv: %d\n",
                       T_glob / 8.0,
                       0.732421875*((float)T_datalog[datalogger_q_r_cached+64] - (float)T_datalog[datalogger_q_r_cached])/8.0,
                       TSNS_ADC_value_12_bit_avg[0],
                       VTCMV_glob);
                // note: 0.732421875 is 48kHz (ADC) / 2 (number of ADC chan) / 128 (ADC_BUFF half-size) / 4 (ADC-> datalog mult) / 64 (number of logged samples averaged over)
            }
        }
        // poll other core for signals
        else if (multicore_fifo_rvalid()) {
            int mcdlsig = multicore_fifo_pop_blocking();
            if ((mcdlsig & MC_DL_FLAG_MASK )== MC_DL_TRIG) {
                // check if these writes will flow to the next sector.
                // Sector number @ bit 12
                if((datalogging_waddr&0x1000) != ((datalogging_waddr+128*3)&0x1000)) {
                    printf("clearing sector...");
                    W25_Clear_Sector_Blocking((datalogging_waddr+128*3)&(~0xFFF));
                    printf("\t\tclear done (status %d)\n",W25_Read_Status_1());
                }

                datalogger_q_r = mcdlsig & MC_DL_BUFF_I_MASK;
                datalogger_q_r_cached = datalogger_q_r;
                //printf("cursor at %d\n",datalogger_q_r);

                //printf("writing ISNS data [0x%08X]...",datalogging_waddr);
                W25_Program_Page_Blocking(datalogging_waddr,(uint8_t *)&ISNS_ADC_value_12_bit_avg[datalogger_q_r],128);
                printf("Logging... [1/3 %0x06X (%d)]",datalogging_waddr,W25_Read_Status_1());
                datalogging_waddr += 128;

                //printf("writing TSNS data [0x%08X]...",datalogging_waddr);
                W25_Program_Page_Blocking(datalogging_waddr,(uint8_t *)&TSNS_ADC_value_12_bit_avg[datalogger_q_r],128);
                printf(" [2/3 %0x06X (%d)]",datalogging_waddr,W25_Read_Status_1());
                datalogging_waddr += 128;

                //printf("writing TSNS data [0x%08X]...",datalogging_waddr);
                W25_Program_Page_Blocking(datalogging_waddr,(uint8_t *)&dutycycle_datalog[datalogger_q_r],128);
                printf(" [3/3 %0x06X (%d)]\n",datalogging_waddr,W25_Read_Status_1());
                datalogging_waddr += 128;
            }
        }
    }

    reboot:
    printf("REBOOT!\n");
    reset_usb_boot(0,0);
    return 0;
}

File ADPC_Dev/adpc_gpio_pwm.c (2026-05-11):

#include "adpc_gpio_pwm.h"
#include "ADPC_cfg.h"

#include "hardware/gpio.h"
#include "hardware/pwm.h"
#include <stdio.h>

mphb2_gpio_pwm_t hb_1B = {
        .pwm_a_pin = PWM_B_1_PIN,
        .pwm_c_pin = PWM_D_1_PIN,
        .ph_en_pin = PH_EN_B1_PIN,
        .initialized = false,
};
mphb2_gpio_pwm_t hb_2B = {
        .pwm_a_pin = PWM_B_2_PIN,
        .pwm_c_pin = PWM_D_2_PIN,
        .ph_en_pin = PH_EN_B2_PIN,
        .initialized = false,
};
mphb2_gpio_pwm_t hb_3B = {
        .pwm_a_pin = PWM_B_3_PIN,
        .pwm_c_pin = PWM_D_3_PIN,
        .ph_en_pin = PH_EN_B3_PIN,
        .initialized = false,
};
mphb2_gpio_pwm_t hb_1A = {
        .pwm_a_pin = PWM_A_1_PIN,
        .pwm_c_pin = PWM_C_1_PIN,
        .ph_en_pin = PH_EN_A1_PIN,
        .initialized = false,
};
mphb2_gpio_pwm_t hb_2A = {
        .pwm_a_pin = PWM_A_2_PIN,
        .pwm_c_pin = PWM_C_2_PIN,
        .ph_en_pin = PH_EN_A2_PIN,
        .initialized = false,
};
mphb2_gpio_pwm_t hb_3A = {
        .pwm_a_pin = PWM_A_3_PIN,
        .pwm_c_pin = PWM_C_3_PIN,
        .ph_en_pin = PH_EN_A3_PIN,
        .initialized = false,
};

mphb2_gpio_pwm_t *mphb2_arr[6] = {
        &hb_1A,
        &hb_2A,
        &hb_3A,
        &hb_1B,
        &hb_2B,
        &hb_3B
        };

const char *mphb_port_names[] = {
"HB1A", "HB2A", "HB3A", "HB1B", "HB2B", "HB3B"
};

volatile uint32_t mphb_pwm_cm_level = MPHB_PWM_WRAP/2;

void mphb_gpio_init(mphb_port_t i) {
    int pwm_ab_pin = mphb2_arr[i]->pwm_a_pin;
    int pwm_cd_pin = mphb2_arr[i]->pwm_c_pin;
    int ph_en_pin = mphb2_arr[i]->ph_en_pin;

    gpio_init(pwm_ab_pin);
    gpio_init(pwm_cd_pin);
    gpio_set_function(pwm_ab_pin,GPIO_FUNC_PWM);
    gpio_set_slew_rate(pwm_ab_pin, GPIO_SLEW_RATE_FAST);
    gpio_set_function(pwm_cd_pin,GPIO_FUNC_PWM);
    gpio_set_slew_rate(pwm_cd_pin, GPIO_SLEW_RATE_FAST);
    gpio_set_dir(pwm_ab_pin,GPIO_OUT);
    gpio_set_dir(pwm_cd_pin,GPIO_OUT);

    uint slice = pwm_gpio_to_slice_num(pwm_ab_pin);
    uint ch_A = pwm_gpio_to_channel(pwm_ab_pin);
    uint ch_C = pwm_gpio_to_channel(pwm_cd_pin);

    mphb2_arr[i]->slice = slice;
    mphb2_arr[i]->ch_A = ch_A;
    mphb2_arr[i]->ch_C = ch_C;

    pwm_config cfg = pwm_get_default_config();
    // 125MHz --> 100khz | 125M / 1.25 = 100MHz | Top = 500; Level = 1000
    pwm_config_set_clkdiv(&cfg, 1.25f);
    pwm_config_set_wrap(&cfg, MPHB_PWM_WRAP);
    pwm_init(slice,&cfg,false);
    mphb_set_dlevel(i, 0);


    // TODO: check connection with PH_EN_PIN as input...
    gpio_init(ph_en_pin);
    gpio_put(ph_en_pin, 0);
    gpio_set_dir(ph_en_pin, GPIO_OUT);

    mphb2_arr[i]->initialized = true;
}

//  pass a mask constructed like so:
// (1U<<HB1A) | (1U<<HB2B)
// or whatever your situation is
//  Will automatically assign phase shifts (PWM counter offsets) based on number of bits masked.
//  Probably best to perform all necessary mphb_gpio_inits **first**.
void mphb_setup_multiphase_masked(uint32_t phases_mask) {
    int n = __builtin_popcount(phases_mask); // number of bits set in mask
    int ni = 0; // counter as we find bits in mask
    for(int i = HB1A; i<=HB3B; i++) { // go through the bits
        if ( (phases_mask>>i) & 0x1 ) pwm_set_counter(mphb2_arr[i]->slice, (ni*mphb_pwm_cm_level)/n);
    }
}

void mphb_set_levels(mphb_port_t i, uint level_A, uint level_C) {
    pwm_set_chan_level(mphb2_arr[i]->slice,mphb2_arr[i]->ch_A,level_A);
    pwm_set_chan_level(mphb2_arr[i]->slice,mphb2_arr[i]->ch_C,level_C);
}

void mphb_set_levels_all(uint level_A, uint level_C) {
    for(mphb_port_t i = 0; i<6; i++) {
        mphb_set_levels(i, level_A, level_C);
    }
}

void mphb_set_dlevel(mphb_port_t i, int dlevel) {
    mphb_set_levels(i, mphb_pwm_cm_level + (dlevel + 1)/2, mphb_pwm_cm_level - (dlevel/2) );
}

void mphb_set_dlevel_all(int dlevel) {
    for(mphb_port_t i = 0; i<6; i++) {
        mphb_set_dlevel(i, dlevel);
    }
}

// takes a -1.0 to 1.0 duty cycle float and sets the levels among **phase-enabled* phases
// so that they are dithered *around* that duty cycle.
void mphb_set_dlevel_all_spatial_dithering(float d) {
    float Nph = 0; // number of active phases
    for(mphb_port_t i = HB1A; i<=HB3B; i++) Nph += mphb2_arr[i]->ph_en;
//    printf("%d\n",Nph);
    float n = 0;
    for(mphb_port_t i = HB1A; i<=HB3B; i++) {
        if(!mphb2_arr[i]->ph_en) continue; // only do active phases.
        // convert to PWM value
        // TODO: 500 is hardcoded and also... wrong?
        float flevel = (500*d + (1+n)/(2*Nph));
//        printf("%.2f\t",flevel);
         mphb_set_dlevel(i, (int) flevel);
//        printf("%d\n",level);
        n++;
    }
}


void mphb_set_ph_en(mphb_port_t i, bool enable) {
    gpio_put(mphb2_arr[i]->ph_en_pin, enable);
    mphb2_arr[i]->ph_en = enable;
}

// sets the enable for all **initialized** items.
void mphb_set_ph_en_all(bool enable) {
    for(mphb_port_t i = HB1A; i<=HB3B; i++) {
        if(mphb2_arr[i]->initialized) mphb_set_ph_en(i,enable);
    }
}
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

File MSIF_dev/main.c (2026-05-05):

#include <stdio.h>
#include <stdlib.h>
#include <stdint.h>
#include <ctype.h>

#include "pico/stdlib.h"
#include "pico/bootrom.h"


#include "hardware/gpio.h"


#include "MSIF_cfg.h"
#include "msif_gpio.h"
#include "msif_analog.h"
#include "msif_adc.h"
#include "msif_peak.h"
#include "msif_proto.h"

// Pin tables (msif_speed_pins / mode / gain / range) and the bit pack/unpack
// helpers (msif_gpio_read_field, msif_gpio_write_field) live canonically in
// msif_gpio.{h,c} — included via "msif_gpio.h" above. main.c just uses them.

#define MSIF_DMM_PULSE_MS 2000 // Allows for a 2ms pulse to be seen on a DMM

// Print the hello banner and command help. Called at startup AND on '?'.
// The startup copy is usually dropped because VS Code Serial Monitor
// doesn't assert DTR until after the firmware has already printed and
// the pico_stdio_usb layer silently drops output with no host connected,
// so '?' is the reliable way to retrieve this after a late connect.
static void msif_print_banner(void) {
    printf("OTHER GUY'S CAPSTONE BIG TWO SIX\n");
    printf("Commands: s=status, o=ONLINE, r=RESET_SCAN c=CLR_EC, "
           "R=RESET_SCAN_DMM C=CLR_EC_DMM, "
           "S=SPEED M=MODE G=GAIN N=RANGE (inc), f=FMASS, v=FMASS_V, "
           "F=SWEEP P=PARK, K=PK_SWEEP T=PK_PARK, "
           "a=ANALOG, d=CS_TOGGLE l=LOOPBACK, "
           "i=EC_READ A=ADC_SNAP, ?=help, q=BOOTSEL\n");
    printf("Protocol: ':<CMD> <args>' (e.g. ':MASS 28.5', ':HELP' for list).\n");
}

// Read a number from the serial port into buf, terminated by CR/LF or timeout.
// Returns the number of characters read (0 if nothing came in). Used by the
// 'f' command to collect a floating-point mass argument.
static int msif_read_line(char *buf, int maxlen, uint32_t timeout_us) {
    int n = 0;
    while (n < maxlen - 1) {
        int c = stdio_getchar_timeout_us(timeout_us);
        if (c == PICO_ERROR_TIMEOUT) break;
        if (c == '\r' || c == '\n') {
            if (n == 0) continue;
            break;
        }
        buf[n++] = (char)c;
    }
    buf[n] = '\0';
    return n;
}

static bool msif_parse_float(const char *buf, float *value) {
    char *endptr;
    float parsed;

    while (isspace((unsigned char)*buf)) buf++;
    if (*buf == '\0') return false;

    parsed = strtof(buf, &endptr);
    if (buf == endptr) return false;

    while (isspace((unsigned char)*endptr)) endptr++;
    if (*endptr != '\0') return false;

    *value = parsed;
    return true;
}

static bool msif_read_float_arg(const char *prompt, float *value) {
    char buf[32];
    int n = msif_read_line(buf, sizeof(buf), 1000);

    if (n == 0) {
        printf("%s", prompt);
        n = msif_read_line(buf, sizeof(buf), 10 * 1000 * 1000);
        if (n == 0) {
            printf("timeout, no value entered\n");
            return false;
        }
    }

    if (!msif_parse_float(buf, value)) {
        printf("invalid number: '%s'\n", buf);
        return false;
    }
    return true;
}

// Bench CLI pulse helper: delegates the actual GPIO toggle to msif_gpio_pulse
// (canonical in msif_gpio.c) and adds a printf so the operator sees confirmation.
static void msif_pulse_output(uint pin, uint32_t ms, const char *label) {
    msif_gpio_pulse(pin, ms);
    printf("%s pulsed (%lums)\n", label, (unsigned long)ms);
}

static void msif_print_analog_status(void) {
    msif_dac_snapshot_t snap;

    if (!msif_dac_snapshot(&snap)) {
        printf("ANALOG: DAC layer not initialised\n");
        return;
    }

    printf("ANALOG: DEVID=0x%04X SYNC=0x%04X CONFIG=0x%04X "
           "GAIN=0x%04X STATUS=0x%04X\n",
           snap.devid, snap.sync, snap.config, snap.gain, snap.status);
    printf("DAC: A=0x%04X B=0x%04X C=0x%04X D=0x%04X\n",
           snap.dac[0], snap.dac[1], snap.dac[2], snap.dac[3]);
    printf("FMASS calibration: slope=%.6f V/AMU, offset=%.6f V\n",
           MSIF_FMASS_CAL_SLOPE_V_PER_AMU,
           MSIF_FMASS_CAL_OFFSET_V);
}
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

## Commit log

2025-12-11 Manual ADC buffer fills [bug: ADC FIFO not flushed between batches]
    [main.c]
2025-12-11 PI control with fixed current target
    [main.c]
2025-12-11 Integer PI controller [Bug: integrator bounded too hard]
    [main.c]
2025-12-11 Integer PI control (roughly 100Hz)
2025-12-12 Working ADC round-robin and DMA daisy-chain
2025-12-12 Broken Buggy PI control
    [capstone_dsp.c, main.c]
2025-12-12 Reorganized ADC and DMA inits into dedicated header
2025-12-12 ADC/DMA stop/start commands working
2025-12-13 Working PI control [BUG: pulse-train noise appears]
    [capstone_dsp.c]
2025-12-17 Starting TC conversions
    [KTYPE TC Voltages.csv]
2025-12-17 Temperature Readings Kind of Accurate?
2025-12-17 Adapted W25 driver from previous work
2025-12-17 Fixed sector erase to align with page-sector alignemnt
    [main.c]
2026-01-23 Really stupid bug fix in flash write
    [capstone_w25.c]
2026-01-23 added PWM mode for debugging measurements
2026-01-23 PWM Current Readouts for G=150 Diffamp
2026-02-02 saving [BUGGY] interrupt-based logging regime
    [capstone_adc.c, capstone_w25.c, main.c]
2026-02-03 Rudimentary Datalogging Working [BUG: jumpy TC measurement]
    [main.c]
2026-02-11 UI Bug Fixes and Updated Current Control Circuit
    [main.c]
2026-02-26 Started work on MCP356xR driver (testing on MCP3462R)
2026-02-26 Data analysis & up-to-date
    [Vout and VTC (21A).csv, Vout and VTC (30A).csv, Vout and VTC (33A).csv]
2026-02-26 Piecing together ADC reading code
2026-02-26 Progress of driver. Still not getting real ADC readings.
2026-03-03 Capstone revs: calculating dT/dt (sloppy, on command)
    [main.c, mcp3x6xR.c]
2026-03-14 Two phase and ADC driver development
2026-03-14 ADA4255 driver development. Succesfully read config register and got expected default val (0x4).
2026-03-14 ADA4255 Driver Readme started.
2026-03-14 Added symlink for driver directory.
2026-03-19 Adding ADC0, PGIA GPIO, and TMP_SNS pin defs
2026-03-20 Added test for ADC IRQ pin
2026-03-20 [WIP] Started PIO for ADC continuous reading.
2026-03-22 Started anew on the PIO for ADC reading. [Compiles]
2026-03-22 [WIP] Program to read samples with PIO and DMA. Times out. Needs scoping!
2026-03-22 Updated pin defs for ADPC and Breadboard
2026-03-22 DMA IRQ clear.
2026-03-22 [Compiles] Replaced pico W with pico 2 on breadboard for PIO wait jmppin.
    [mcp3x6xR.c, mcp_pio.c]
2026-03-22 [WORKS] 100 samples with PIO, DMA and MCP ADC in continuous mode!!
2026-03-23 Swapped CS literal pin for macro
2026-03-25 [WIP] Started DMA daisy chain setup.
2026-04-13 [WORKS] daisy-chained DMAs
2026-04-13 [WORKS] Using alignment and DMA Ring feature. No need for write-address resets!
    [mcp_pio.c]
2026-04-13 Moved mcp pio files to driver directory.
2026-04-13 [WIP: bad adc vals] ADPC_ADC starting
2026-04-13 [Works] Fixed printf issue, teehee!
2026-04-13 Replaced literals with macros in config regs.
    [ADPC_ADC.c]
2026-04-13 Fixed number of cfgs and included prototype in header file
    [mcp3x6xR.c]
2026-04-14 MSIF: add digital input pin defs and 's' status command
    First pass at MSIF hardware I/O per Isaiah's getting-started guide.
    Defines MSIF_EMIS_OK_IN_PIN (GPIO30) and MSIF_SCAN_IN_PROGRESS_IN_PIN
    (GPIO31) from the schematic, configures them as inputs, and adds an
    's' command to the USB-serial input loop that reads and prints both
    pin states.
    Both signals come from the QMS-112 through U21 (74AUP2G14DW inverting
    Schmitt), so the active-low QDP signals read active-high at the GPIO
    (gpio_get == 1 means "active").
    [main.c]
2026-04-14 MSIF: add digital output pin defs and 'o' ON_LINE toggle
    Defines all 14 MSIF digital output pins from the schematic:
    ON_LINE=GP16, SPEED_3=GP17, GAIN_1=GP18, GAIN_0=GP19,
    MODE_1=GP20, MODE_0=GP21, RANGE_0=GP22, MODE_2=GP23,
    CLR_EC=GP24, RANGE_1=GP25, RESET_SCAN=GP26,
    SPEED_0=GP27, SPEED_1=GP28, SPEED_2=GP29.
    Extends msif_gpio_init() to configure each as GPIO_OUT defaulting
    to 0 (MOSFET off → QMS signal inactive), renames the print helper
    to msif_print_digital_io() so it dumps both the inputs and the
    current output states, and adds an 'o' serial command that toggles
    MSIF_ON_LINE_PIN for scope-probe verification of the BSS138 level
    shift path at the QDP connector.
    Still no mode/spe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
    [main.c]
2026-04-14 MSIF: use gpio_get_out_level() for output pins to fix synchronizer race
    gpio_get() reads GPIO_IN through a 2-stage synchronizer, so reading an
    output pin immediately after gpio_xor_mask/gpio_put returns stale data.
    Fix by using gpio_get_out_level() which reads the SIO GPIO_OUT register
    directly. Affects both msif_print_digital_io() and the 'o' toggle
    handler in main().
    [main.c]
2026-04-14 MSIF: add debug commands for all 14 output pins
    Previously only ON_LINE (via 'o') was reachable from the serial
    console. Adds six more commands so every MSIF output can be exercised
    for multimeter/scope verification at the QDP connector:
    r pulse RESET_SCAN high for ~10ms
    c pulse CLR_EC high for ~10ms
    S increment SPEED (4-bit, wraps at 16)
    M increment MODE (3-bit, wraps at 8)
    G increment GAIN (2-bit, wraps at 4)
    N increment RANGE (2-bit, wraps at 4) -- 'N' for raNge ('r' taken)
    Increment instead of per-bit toggles for the multi-bit fields so we
    don't eat the letter alphabet; cycling exercises every bit
    combination and the printed binary value lets you cross-check each
    p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
    [main.c]
2026-04-14 MSIF: add '?' help command to work around DTR-drop on startup
    pico_stdio_usb silently drops printf output when tud_cdc_connected()
    returns false (DTR not yet asserted), which means the startup banner
    printed during stdio_init_all + sleep_ms(1000) is lost whenever the
    host serial monitor connects late. VS Code's Serial Monitor in
    particular doesn't assert DTR until after the firmware has already
    printed, so you'd open COM8 and see nothing.
    Extract the banner/help text into msif_print_banner() and wire it to
    a new '?' command so the user can retrieve it on demand after a late
    connect. Also update the fallback "Input received!" hint to mention
    '?'.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
    [main.c]
2026-04-14 Re-rendered Schematics (PNG)
2026-04-16 [works, wip] Fixing ADPC_ADC init funcs
    [ADPC_ADC.c]
2026-04-16 [works, wip] Fixing config
    [ADPC_ADC.c, mcp3x6xR.c]
2026-04-17 [broken] Trying to set up cfg struct and usage.
    [ADPC_ADC.c, mcp3x6xR.c]
2026-04-17 [still works] Changed configure() prototype to take struct pointer
2026-04-17 [works] removed prints in configure()
2026-04-17 Driver documentation (PIO, etc)
2026-04-19 MSIF: add DAC80504 analog output stack + bench diagnostics
    New DAC80504 driver (src2/dac80504_driver/) handles the GPIO 42 CS#/LDAC#
    short bodge by keeping all four channels in asynchronous-update mode
    (SYNC=0x0000) and skipping duplicate LDAC pin init when pin_ldac == pin_cs.
    New msif_analog layer wraps the driver with board-level gain correction and
    the FMASS mass->voltage calibration hooks (slope/offset live in MSIF_cfg.h,
    populated from the Phase H bench sweep). Parks MCP3462RT ADC CS# (GPIO 37)
    HIGH at init so the unwritten ADC driver can't stomp on DAC reads via the
    shared SPI bus.
    New serial commands:
    f <mass> - set FMASS via calibration (channel A, OPA4197 gain ~= 4)
    v <volts>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
    [MSIF_cfg.h, dac80504.c, dac80504.h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]
2026-04-19 Pin functions listed
    [RP2350 Pin Functions.csv]
2026-04-19 Decided SPI Flash Fix pin/connector assigments and next steps. Wrote explainer text.
2026-04-20 [works] Streams ADC batch data over USB CDC mode
2026-04-20 Easier streaming without reboots; user input for byte count.
    [script.py]
2026-04-20 [wip, works] literal SPI writes seem to work repeatably. Need to compartmentalize and sort out why configure() doesn't work.
    [ada4255.c]
2026-04-20 Destinatin for ADC logging files
2026-04-20 ADPC and MSIF Schematics
2026-04-20 Added EDA Projects (EasyEDA zips and KiCad versions of those zips)
    [ADPC Connections.kicad_sch, ADPC TC Interface.kicad_sch, BackupProjects_maxim.laplante_personal_0_20260420.kicad_pcb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]
2026-04-21 [fixed] Replaced **ADC_CS** with **PGIA_CS**. Stupid!
    [ada4255.c]
2026-04-21 Added PGIA driver
2026-04-21 Set timer and dly to 0 for scan mode.
2026-04-21 Removed row printing
2026-04-21 Moving full-board data streaming away from MCP ADC development.
2026-04-21 Rolled back for just ADC stuff.
2026-04-21 Fixed PWM init order
    [ADPC_ADC.c]
2026-04-24 MSIF: add MCP3462RT ADC stack + SPI bus-mode arbitration
    Wraps the existing mcp3x6xR driver in msif_adc.{c,h} for ion-current reads
    off QDP EC-. Both DAC and ADC share SPI0 (SCK/MOSI/MISO) with only CS#
    unique, and their required SPI modes conflict (DAC=mode 1, ADC=mode 0), so
    every public bus-touching function in msif_analog.c and msif_adc.c now
    re-asserts its own SPI format before any transaction. main.c gains `i`
    (one-shot ion read) and `A` (ADC register snapshot) commands.
    Driver quirks worked around inline: this worktree snapshot of mcp3x6xR
    forgets to store spi_inst_t* into mcp_info_t, and mcp_configure() only
    writes 3 of 4 CFG registers with a broken readback check. Both documented
    a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
    [MSIF_cfg.h, main.c, msif_adc.c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]
2026-04-24 MSIF: add FMASS sweep + park commands, averaged EC- reads
    Closes the 'set mass, read ion current' loop in firmware so Phase H
    calibration and basic TPD-style logging don't require manual per-point
    serial typing.
    F sweep FMASS v_start->v_end over N steps; at each step settle,
    average MSIF_ADC_AVG_SAMPLES one-shot EC- reads, emit CSV row
    (step,t_ms,v_fmass,ec_code,v_adc_diff,v_ec,status). Parks FMASS
    at 0 V on exit. Any keypress aborts.
    P park FMASS at a fixed voltage and stream averaged EC- readings
    every MSIF_ADC_PARK_PERIOD_MS until a keypress or configured
    duration elapses. Same CSV schema minus the step column.
    Both rely on a new msif_adc_read_ec_avg() hel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
    [MSIF_cfg.h, main.c, msif_adc.c]
2026-05-04 Update CMakeLists.txt to include new source files and configure UART settings; remove outdated schematic PDF.
2026-05-05 Refactor calibration plan documentation to streamline content and focus on essential calibration parameters. Removed extensive details on stages and procedures, retaining only critical information re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
2026-05-06 Fixed MCLK, integrated PWM to streaming code, working on script and data output.
    [ADPC_ADC.c, adpc_data_streaming.c, mcp3x6xR.c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]
2026-05-07 CDC user input started. Starting dual-ADC operation.
2026-05-07 Got rid of finite DMA cycles. User break required.
2026-05-09 Shell improvements [rstream end still broken!]
    [adpc_app.c, adpc_app_funcs.c]
2026-05-09 ADC readout commands 'r0' and 'r1' working!
2026-05-09 [doesn't work] sample-by-sample ictl
    [adpc_app.c]
2026-05-10 Programmable current supply!
2026-05-10 Init and ADC printing bug fixes
    [adpc_app.c, mcp_pio.c]
2026-05-10 [commit fix!] Forgot to add core1 code.
    [adpc_core1.c]
2026-05-10 ADC read default value
2026-05-10 Corrected sign extension for ADC prints
    [adpc_app.c]
2026-05-10 Added fourth MPHB card. Fixed "level" command to take float argument
    [adpc_app.c]
2026-05-11 Drop unused MSIF_Docs markdowns + ignore personal scratch dir
    Removed:
    - MSIF_dev/MSIF_Docs/calibration_plan.md
    - MSIF_dev/MSIF_Docs/user_manual.md
    Added to .gitignore:
    - MSIF_dev/MSIF_Docs/whatever/ — personal scratch, keep untracked
2026-06-23 MSIF: reconcile msif_adc.c with updated MCP driver
    - Pass -1 for the new mclk_pin arg in mcp_spi_init (we use the chip's
    internal clock; mcp_mclk_init is never called).
    - Drop the now-obsolete s_adc.spi workaround — the upstream driver now
    stores the spi instance pointer itself.
    - File-header doc comment was previously stripped by Cursor; leaving
    stripped per archi's call.
    [msif_adc.c]
2026-07-15 Restore msif_adc.c doc header; rename datasheet to Windows-safe filename
    - msif_adc.c: restore documentation header dropped by the June 23 reconcile
    commit, fix stale comment refs (CH0 mux, auto-zero); mux second input now
    CH0 with 7/15 bench note re: checking channels against new wiring
    - Rename 'Synchronizing RP2040s\.pdf' -> 'Synchronizing RP2040s.pdf': the
    backslash filename is invalid on Windows and was corrupting the git index
    [msif_adc.c]
2026-07-16 Fixed AI comments in msif_adc
    [msif_adc.c]
